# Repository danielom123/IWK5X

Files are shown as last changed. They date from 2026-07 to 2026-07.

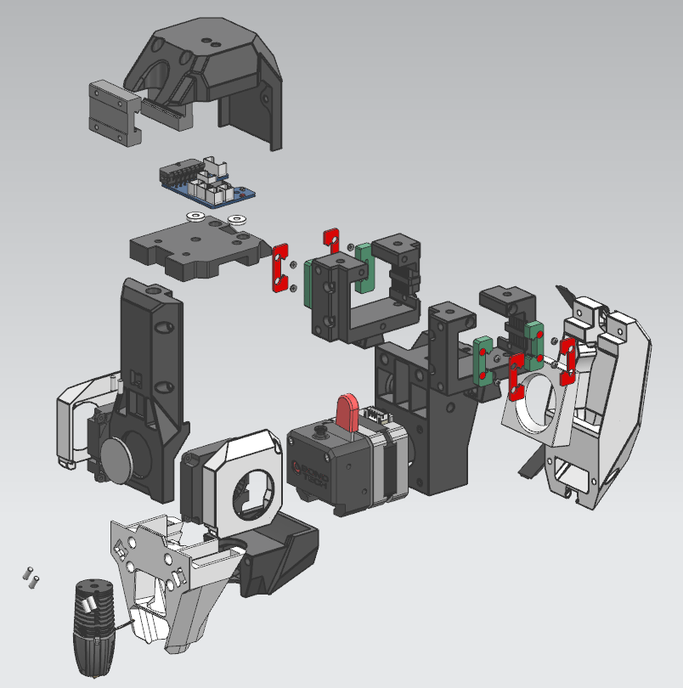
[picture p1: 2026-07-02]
STLs/Toolhead/toolhead_expl_view.png

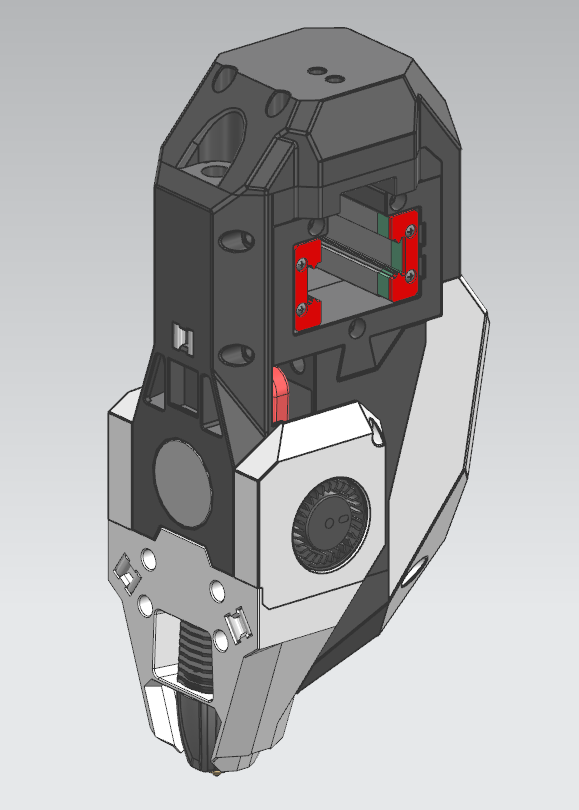
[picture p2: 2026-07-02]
STLs/Toolhead/Toolhead.png

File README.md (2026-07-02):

# IWK5X

> Developed at the [Institute for Materials Technology and Plastics Processing (IWK)](https://www.ost.ch/de/forschung-und-dienstleistungen/technik/maschinentechnik/iwk-institut-fuer-werkstofftechnik-und-kunststoffverarbeitung),
> OST – Ostschweizer Fachhochschule, Rapperswil, Switzerland
>
> **Authors:** Daniel Omidvarkarjan, Daniel Aeschbacher, Simon Grimm, Cedric Kundert
>
> **Paper:** *IWK 5X – An Open-Source Multi-Axis, Multi-Material 3D Printer for Material Extrusion*
> Procedia CIRP 142 (2026) 369–373 · [doi:10.1016/j.procir.2026.05.276](https://doi.org/10.1016/j.procir.2026.05.276)

---
PXL_20230619_124147241 PORTRAIT~2

---

## Overview

The IWK 5X is a custom 5-axis Fused Filament Fabrication (FFF) 3D printer developed at OST's IWK department. It extends a [Voron 2.4r2](https://github.com/VoronDesign/Voron-2) CoreXY platform with an AC-trunnion bridge that adds two rotational degrees of freedom:

| Axis | Rotation about | Type |
| ---- | --- | --- |
| A | Y-axis | Tilt (swivel) |
| C | Z-axis | Rotation |

The additional axes allow complex geometries to be printed without support structures and enable print paths to be oriented along stress flow, improving part strength and surface quality compared to conventional planar MEX.

The complete design files, BOM, and firmware configuration are released for open-source use in this repository.

---

## Hardware

| Component | Details |
| --- | --- |
| Base chassis | Voron 2.4 (CoreXY) |
| Rotational mechanism | AC-trunnion bridge |
| Build volume | Ø220 × 195 mm |
| Structural parts | SLS polyamide 12 (or FFF) |
| Control electronics  | Duet3 WiFi mainboard + DuetX5 expansion |
| Firmware | RepRapFirmware (RRF) |
| Tool changer | Manual - BIQU Hermit Crab V2.0 mechanical interface with custom PCB |
| Printing bed | Heated bed or aluminium mounting plate (interchangeable) |

### Supported Tool Heads

| Process | Description |
| --- | --- |
| FFF | Fused filament fabrication (standard filament extrusion) |
| FGF | Fused granulate fabrication (e.g. Metexon MTX extruder) |
| Fluid extrusion | Viscous materials, silicones (e.g. Viscotec vipro-HEAD 3/3) |
| Post-processing | Milling head and other add-ons via the tool changer interface |

The tool changer interface supports 3 stepper motors, 2 heaters, and 5 temperature sensors/fans.

---

## Software

| Layer | Technology |
| --- | --- |
| Firmware | [RepRapFirmware](https://github.com/Duet3D/RepRapFirmware) via Duet Web Control (DWC) frontend |
| CAM / slicing | Custom Rhinoceros plugin |
| Slicing modes | Conformal, concentric, curvilinear |

---

## Related Work & Extensions

- **Voron 2.4:** [vorondesign.com](https://vorondesign.com/)
- **RepRapFirmware:** [github.com/Duet3D/RepRapFirmware](https://github.com/Duet3D/RepRapFirmware)

---

## Citation

If you use this work, please cite the original publication:

```bibtex
@article{omidvarkarjan2026iwk5x,
  title   = {{IWK 5X} -- An Open-Source Multi-Axis, Multi-Material {3D} Printer for Material Extrusion},
  author  = {Omidvarkarjan, Daniel and Aeschbacher, Daniel and Grimm, Simon and Kundert, Cedric},
  journal = {Procedia CIRP},
  volume  = {142},
  pages   = {369--373},
  year    = {2026},
  doi     = {10.1016/j.procir.2026.05.276}
}
```

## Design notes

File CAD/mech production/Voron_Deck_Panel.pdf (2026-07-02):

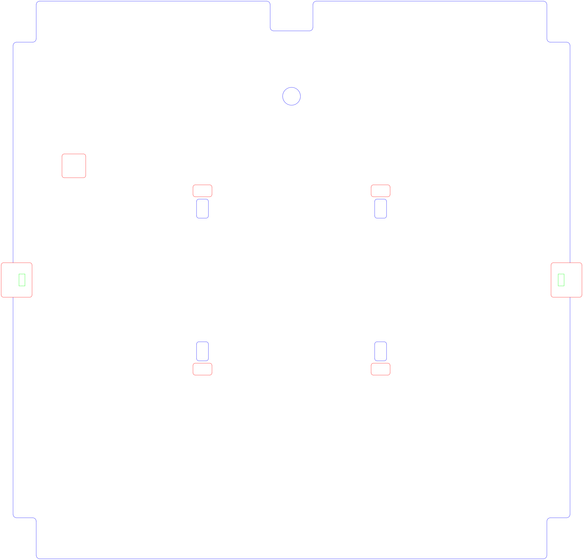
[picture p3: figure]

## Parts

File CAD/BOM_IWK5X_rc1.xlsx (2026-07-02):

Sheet: Voron
Order list |  |  |  |  |  |  | Total price | 4553.88 | CHF |  | Legend
 |  |  |  |  |  |  |  |  |  |  | can be ordered
Subject | 5-axis 3D printer |  |  |  |  |  |  |  |  |  | ordered
 |  |  |  |  |  |  |  |  |  |  | arrived
Pos | Description | Part number | Internal/External | Source | Link | Qty | Unit price | Total price | OK | Comment | under clarification
10 | Power supply 24V 400W | E3D-E-PSU-24V-400W | External | 3DJAKE | Link (https://www.3djake.ch/de-CH/e3d/netzteil) | 1 | 61.30 | 61.30 |  |  | not needed
20 | Linear rail 12mmx400m | 1901044.31 | External | 3dWare | Link (https://www.3dware.ch/Schwarz-eloxierte-Linearschiene-12mm-/-400mm-lang-De.htm) | 1 | 37.95 | 37.95
30 | Rapido Plus Hotend HF Black | PH-A158-05B-15-03 | External | 3DJAKE | Link (https://www.3djake.ch/de-CH/phaetus/rapido-plus-hotend-hf?sai=12879) | 1 | 112.40 | 112.40
40 | Voron 2.4 350mm Rev.A Black | PHWVO0010V.3 | External | 3Dmensionals | Link (https://www.3dmensionals.de/ldo-motors-voron-v2.4r2-drucker-bausatz?number=PHWVO0010V.3) | 1 | 1591.34 | 1591.34
50 | Duet 2 Wifi | 1900348.7 | External | 3dWare | Link (https://www.3dware.ch/Duet-2-Wifi-V1.04-De.htm) | 1 | 242.95 | 242.95
60 | DueX 5 Expansion Board | 1900348.5 | External | 3dWare | Link (https://www.3dware.ch/DueX5-Erweiterungsplatine-f%C3%BCr-Duet-De.htm) | 1 | 139.95 | 139.95
70 | 3D Probe Ø6mm + Spare stylus | n/a | External | Aliexpress | Link (https://www.aliexpress.com/item/1005003466415556.html?curPageLogUid=CYnIz35qAo8W) | 1 | 56.27 | 56.27
80 | Microswitch + PCB | 1900723.1 | External | 3dWare | Link (https://www.3dware.ch/Creality-Endschalter-De.htm) | 5 | 4.95 | 24.75
81 | Power cable CH | 1900824.1 | External | 3dWare | Link (https://www.3dware.ch/CH-Netzkabel-3-polig-auf-C13-De.htm) | 1 | 5.20 | 5.20
90 | Nozzle 0.4mm Bondtech CHT BiMetal | BTE-600-A-CHT-MOS-175-40 | External | 3DJAKE | Link (https://www.3djake.ch/de-CH/bondtech/cht-bimetal-reprap-duese?sai=14008) | 1 | 47.95 | 47.95
100 | Nozzle 0.6mm Bondtech CHT BiMetal | BTE-600-A-CHT-MOS-175-60 | External | 3DJAKE | Link (https://www.3djake.ch/de-CH/bondtech/cht-bimetal-reprap-duese?sai=14009) | 1 | 47.95 | 47.95
110 | Bondtech LGX Extruder | BTE-EXT-LGX | External | 3DJAKE | Link (https://www.3djake.ch/de-CH/bondtech/lgx-extruder) | 1 | 118.70 | 118.70
120 | Slip ring 8P 10A | 421546 | External | Bastelgarage | Link (https://www.bastelgarage.ch/8p-10a-elektrischer-schleifring-250rpm?search=drehdurchf%C3%BChrung) | 1 | 36.90 | 36.90
130 | Nema 23 2.8A 8mm Stepper | 1900509.876 | External | 3dWare | Link (https://www.3dware.ch/NEMA-23-Schrittmotor-XL-1.8-Grad,-2.8A-/-8mm-De.htm) | 1 | 48.95 | 48.95
140 | Nema 17 1.5A 5mm Stepper | 421173 | External | Bastelgarage | Link (https://www.bastelgarage.ch/creality-42-34-stepper-motor-nema-17-schrittmotor?search=nema%2017) | 1 | 19.90 | 19.90
150 | Limit switch roller | 421472 | External | Bastelgarage | Link (https://www.bastelgarage.ch/kw1-103-7-micro-rollenschalter-endschalter?search=endschalter) | 2 | 2.50 | 5.00
160 | Pulley GT2 6mm 20T | 1900952.2 | External | 3dWare | Link (https://www.3dware.ch/GT2-Riemenscheibe-20-Z%C3%A4hne-CoreXY-5mm-Bohrung-De.htm) | 1 | 3.80 | 3.80
170 | Wire AWG24 Black 100m | 422200 | External | Bastelgarage | Link (https://www.bastelgarage.ch/kabel-litzen/litzen-drahte/litze-0-25mm-schwarz-lify-hochflexibel-100m) | 1 | 32.90 | 32.90
171 | Wire AWG20 Black 10m | 420752 | External | Bastelgarage | Link (https://www.bastelgarage.ch/kabel-litzen/litzen-drahte/litze-0-5mm-20awg-schwarz-halogenfrei) | 10 | 0.55 | 5.50
180 | Wire AWG17 black 10m | 1900859.22 | External | 3dWare | Link (https://www.3dware.ch/Litzen-Kabel-1.00-mm178-Schwarz-10-Meter-De.htm) | 1 | 7.45 | 7.45
190 | Fan 4020 24V | 421794 | External | Bastelgarage | Link (https://www.bastelgarage.ch/4020-silent-lufter-24v-radial-reparaturset?search=l%C3%BCfter) | 1 | 7.90 | 7.90
200 | Crimping tool JST/ Dupont/ Molex | 420674 | External | Bastelgarage | Link (https://www.bastelgarage.ch/crimpzange-2820m-0-08-0-5mm?search=crimpzange) | 1 | 34.90 | 34.90
210 | JST XH Set 2.54mm | 420207 | External | Bastelgarage | Link (https://www.bastelgarage.ch/jst-xh-crimp-stecker-und-buchsen-2-54mm-set-40-stuck?search=jst) | 1 | 13.90 | 13.90
220 | JST PH Set 2.0mm | 420381 | External | Bastelgarage | Link (https://www.bastelgarage.ch/jst-ph-crimp-stecker-und-buchsen-2mm-set-40-stuck?search=jst) | 1 | 13.90 | 13.90
230 | Dupont Crimp Set | 420382 | External | Bastelgarage | Link (https://www.bastelgarage.ch/dupont-crimp-stecker-und-buchsen-set-620-stuck?search=dupont) | 1 | 19.50 | 19.50
240 | Capricorn PTFE 2m | CC-XS-175-2 | External | 3DJAKE | Link (https://www.3djake.ch/de-CH/capricorn/xs-ultra-low-friction-ptfe-bowden?sai=3645) | 1 | 25.55 | 25.55
250 | Bondtech LGX Hardened Steel Drive | BTE-15147 | External | 3DJAKE | Link (https://www.3djake.ch/de-CH/bondtech/lgx-steel-drive-train-upgrade-set) | 1 | 42.90 | 42.90
260 | Fan 4010 24V | CRE-4004110083 | External | 3DJAKE | Link (https://www.3djake.ch/de-CH/creality-3d-drucker-ersatzteile/radial-luefter-kit?sai=11411) | 2 | 5.10 | 10.20
270 | Switching regulator | 420478 | External | Bastelgarage | Link (https://www.bastelgarage.ch/mp1584-3a-schaltregler-dc-dc-step-down-abwartswandler?search=step%20down) | 2 | 2.90 | 5.80
290 | Assortment box 15 compartments | 420253 | External | Bastelgarage | Link (https://www.bastelgarage.ch/sortimentskasten-mittel-15-facher?search=sortiment) | 3 | 3.90 | 11.70
300 | Drag chain 10x10mm | 421229 | External | Bastelgarage | Link (https://www.bastelgarage.ch/10x10mm-nylon-kabelschlepp-1m?search=kabelschlepp) | 1 | 13.90 | 13.90
310 | Heated bed D200 | FLS-Q5-HOTBED | External | 3DJAKE | Link (https://www.3djake.ch/de-CH/flsun/heizbett-inkl-druckplattform) | 1 | 30.65 | 30.65
320 | Flexplate D203 | BT-BTFS08DIA | External | 3DJAKE | Link (https://www.3djake.ch/de-CH/buildtak/flexplate-system?sai=7832) | 1 | 65.39 | 65.39
340 | Keystone USB C to A | 1009503 | External | Brack | Link (https://www.brack.ch/delock-keystone-modul-usb2-0-usb-a-usb-c-1009503) | 1 | 11.45 | 11.45
350 | Slewing ring | PRT-02.50-LC | External | igus | Link (https://www.igus.ch/product/iglidur_PRT_02_LC_J4?artnr=PRT-02-50-LC) | 1 | 99.93 | 99.93
380 | JST SM Set 2.54mm | 421196 | External | Bastelgarage | Link (https://www.bastelgarage.ch/jst-sm-2-54mm-crimp-stecker-und-buchsen-set-40-stuck?search=jst) | 1 | 11.90 | 11.90
390 | Carbon tube D10 d8 1m | 421890 | External | Bastelgarage | Link (https://www.bastelgarage.ch/mechanische-bauteile/cfk-stabe-rohre/carbon-rohr-o8xo10mm-1m) | 1 | 10.50 | 10.50
400 | KP08 Bearing block | 1900956.1 | External | 3dWare | Link (https://www.3dware.ch/KP08-8mm-Bohrung-Zinklegierung-Lagerwelle-De.htm) | 4 | 3.00 | 12.00
410 | Belt GT2 9mm 450mm | 1900950.45 | External | 3dWare | Link (https://www.3dware.ch/GT2-Riemen-9mm-breit-450mm-lang-De.htm) | 1 | 2.30 | 2.30
411 | Belt GT2 6mm 480mm | 1900920.48 | External | 3dWare | Link (https://www.3dware.ch/GT2-Riemen-6mm-breit-480mm-lang-De.htm) | 1 | 2.20 | 2.20
420 | Pulley GT2 9mm 20T | 1900949.2 | External | 3dWare | Link (https://www.3dware.ch/GT2-9mm-Riemenscheibe-20-Z%C3%A4hne-8mm-Bohrung-De.htm) | 1 | 4.20 | 4.20
430 | Pulley GT2 6mm 40T | 1900944.4 | External | 3dWare | Link (https://www.3dware.ch/GT2-Riemenscheibe-40-Z%C3%A4hne-8mm-Bohrung-De.htm) | 2 | 5.95 | 11.90
440 | Pulley GT2 9mm 60T | 1900949.6 | External | 3dWare | Link (https://www.3dware.ch/GT2-9mm-Riemenscheibe-60-Z%C3%A4hne-8mm-Bohrung-De.htm) | 1 | 8.20 | 8.20
450 | XT30 Connector | 422220 | External | Bastelgarage | Link (https://www.bastelgarage.ch/xt30-stecker-male-und-female?search=xt30) | 3 | 4.50 | 13.50
460 | Solder | 421633 | External | Bastelgarage | Link (https://www.bastelgarage.ch/werkstattbedarf/lotstation-und-zubehor/engineer-swf-08-lotzinn-14g-bleifrei-0-8mm-sn96-5-ag3-cu0-5) | 1 | 15.90 | 15.90
470 | Flange bearing F695ZZ | 1900911.27 | External | 3dWare | Link (https://www.3dware.ch/Rillenkugellager-mit-Flansch-F695ZZ-De.htm) | 8 | 1.50 | 12.00
489 | Threaded insert M3 50pcs | 422091 | External | Bastelgarage | Link (https://www.bastelgarage.ch/3d-drucker/zubehor-3d-druck/m3x6mm-gewindeeinsatze-messing-insert-50stk) | 1 | 6.90 | 6.90
490 | Threaded insert M5 50pcs | 422201 | External | Bastelgarage | Link (https://www.bastelgarage.ch/3d-drucker/zubehor-3d-druck/m5x8mm-gewindeeinsatze-messing-insert-50stk) | 1 | 10.90 | 10.90
491 | Threaded insert M6 50pcs | 422202 | External | Bastelgarage | Link (https://www.bastelgarage.ch/m6x8mm-gewindeeinsatze-messing-insert-50stk?search=gewinde) | 1 | 14.90 | 14.90
500 | Electromagnet 8kg | 421586 | External | Bastelgarage | Link (https://www.bastelgarage.ch/mechanische-bauteile/magnete/5v-elektromagnet-8kg-haftkraft) | 1 | 9.50 | 9.50
510 | Relay 2-channel | 420010 | External | Bastelgarage | Link (https://www.bastelgarage.ch/2-kanal-relais-modul-5v?search=relais) | 1 | 6.90 | 6.90
520 | Heat shrink tubing | 420029 | External | Bastelgarage | Link (https://www.bastelgarage.ch/werkstattbedarf/diverses/schrumpfschlauch-set-diverse-farben-55-stuck-total-15m) | 1 | 9.90 | 9.90
530 | Switching regulator | 420103 | External | Bastelgarage | Link (https://www.bastelgarage.ch/lm2596-schaltregler-dc-dc-step-down-abwartswandler?search=step-down) | 2 | 4.90 | 9.80
540 | Push button Green | 420330 | External | Bastelgarage | Link (https://www.bastelgarage.ch/bauteile/schalter-taster/arcade-taster-button-beleuchtet-33mm-grun) | 1 | 4.50 | 4.50
550 | Push button Red | 420328 | External | Bastelgarage | Link (https://www.bastelgarage.ch/bauteile/schalter-taster/arcade-taster-button-beleuchtet-33mm-rot) | 1 | 4.50 | 4.50
560 | Cable ties 3mm 100pcs | 420646 | External | Bastelgarage | Link (https://www.bastelgarage.ch/werkstattbedarf/diverses/schwarze-3x100mm-nylon-kabelbinder-100-stuck) | 1 | 3.90 | 3.90
570 | 2K Epoxy UHU | 422137 | External | Bastelgarage | Link (https://www.bastelgarage.ch/werkstattbedarf/klebstoff-epoxidharze/uhu-plus-endfest-zweikomponenten-epoxidkleber-33g) | 1 | 12.90 | 12.90
590 | Printed parts SLS/FFF |  | External | JLC3DP | Link (https://jlc3dp.com/de?spm=Jlc3dp.Homepage.1001) | 1 |  | 0.00
600 | Base plate |  | External | JLCCNC | Link (https://jlccnc.com/) | 1 | 300.00 | 300.00
610 | Kinematic components swivel table |  | Internal | Mech-Workshop |  | 1 | 1000.00 | 1000.00
620 |  |  |  |  |  |  |  | 0.00
630 |  |  |  |  |  |  |  | 0.00
640 |  |  |  |  |  |  |  | 0.00
650 |  |  |  |  |  |  |  | 0.00
660 |  |  |  |  |  |  |  | 0.00
670 |  |  |  |  |  |  |  | 0.00
680 |  |  |  |  |  |  |  | 0.00
690 |  |  |  |  |  |  |  | 0.00
700 |  |  |  |  |  |  |  | 0.00
710 |  |  |  |  |  |  |  | 0.00
720 |  |  |  |  |  |  |  | 0.00
730 |  |  |  |  |  |  |  | 0.00

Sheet: Dropdowns
Int/Ext | Supplier
Internal | 3dWare
External | Mädler
 | Schweighofer
 | Galaxus
 | Bastelgarage
 | Amazon
 | Mech-Workshop
 | Blexon
 | Durovis
 | Aliexpress
 | 3DJAKE
 | 3Dmensionals
 | igus
 | Brack
 | IWK
 | JLC3DP
 | JLCCNC

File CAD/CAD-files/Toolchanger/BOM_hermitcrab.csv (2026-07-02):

ID | Name | Designator | Footprint | Quantity | Manufacturer Part | Manufacturer | Supplier | Supplier Part | Price | Pins | 3DModel
1 | XD-ZH-12PWT | U1 | CONN-SMD_12P-P1.50_HCTL_HC-ZH-12PWT | 1 | XD-ZH-12PWT | XUNDA(讯答) | LCSC | C17700467 | 0.167 | 14 | CONN-SMD_12P-P1.50_HCTL_HC-ZH-12PWT
2 | MX128-2.54-04P-GN01-CU-Y-A | HOTENDS | CONN-TH_4P-P2.54_MX128-2.54-GN01-04P-CU-Y-A | 1 | MX128-2.54-04P-GN01-Cu-Y-A | MAX(迈旭) | LCSC | C5188444 | 0.375 | 4 | CONN-TH_4P-P2.54_MX128-2.54-GN01-04P-CU-Y-A
3 | _ | NONE |  | 1
4 | YTC1P-3010-01 | CN1,CN3,CN4,CN5,CN6,CN7,CN8,CN9,CN10,CN11,CN12,CN13,CN14,CN15,CN16,CN17,CN18,CN19,CN20,CN21,CN22,CN23,CN24,CN25 | TESTPOINT-SMD_BD2.0_C9900030651 | 24 | YTC1P-3010-01 | YIYUAN(怡远) | LCSC | C5221282 | 0.134 | 1
5 | YZ90415045R-01 | U3,U6,U9,U10,U11,U12,U13,U14 | SMD-1_BD2.0-H10.0 | 8 | YZ90415045R-01 | Xinyangze(鑫扬泽) | LCSC | C5157399 | 0.395 | 1 | SMD-1_BD2.0-H10.0
6 | HDGC1002WVD-S-2X6P | LOWPOWER | CONN-SMD_12P-P1.00_HDGC_HDGC1002WVD-S-2X6P | 1 | HDGC1002WVD-S-2X6P | HDGC(华德共创) | LCSC | C3041208 | 0.433 | 14 | CONN-SMD_12P-P1.00_HDGC_HDGC1002WVD-S-2X6P

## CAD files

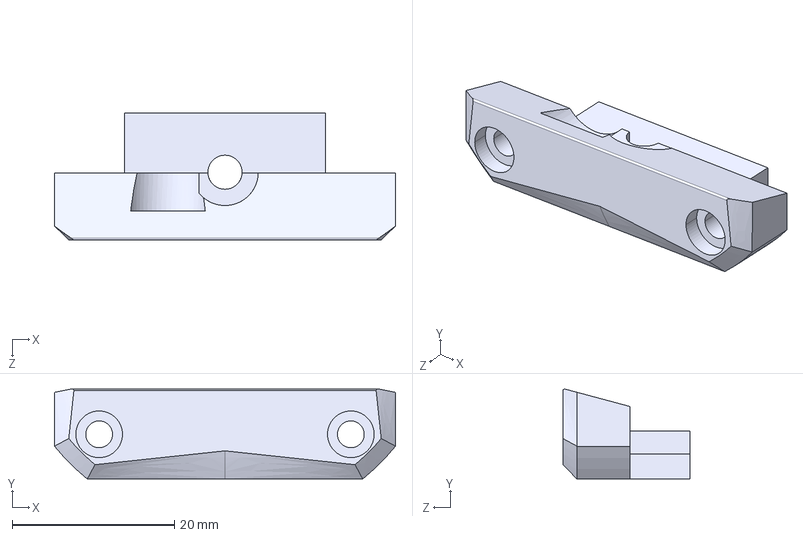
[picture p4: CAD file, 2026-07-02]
CAD/bought-in parts/LGX-Interface-Plug-V1.0.STEP
42.0 x 11.1 x 15.7 mm

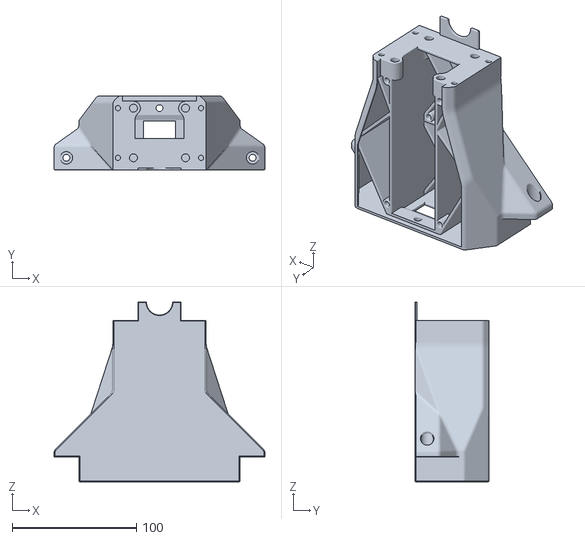
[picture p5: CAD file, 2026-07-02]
STLs/ac_bridge/tronnion_sidepillar_right.stl
170.0 x 60.0 x 145.0

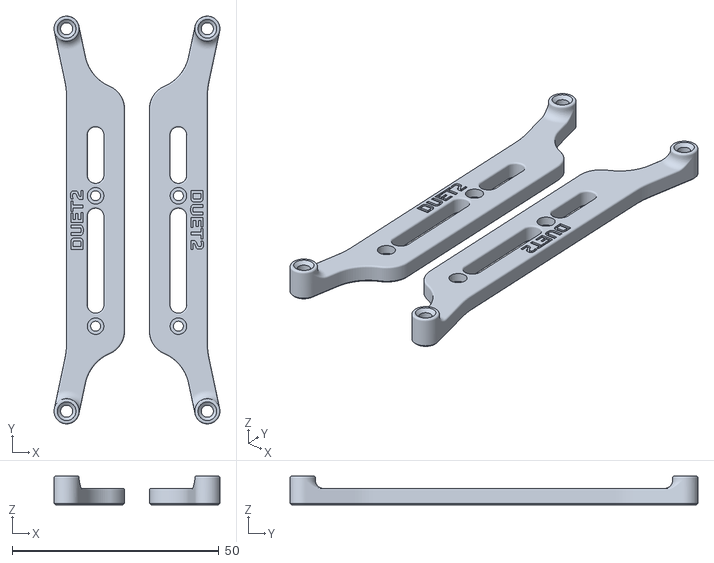
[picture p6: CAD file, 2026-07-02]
STLs/Electronics_Bay/Controller_Mounts/Duet2_Duet3Mini5_bracket_set.stl
40.1 x 98.5 x 7.00

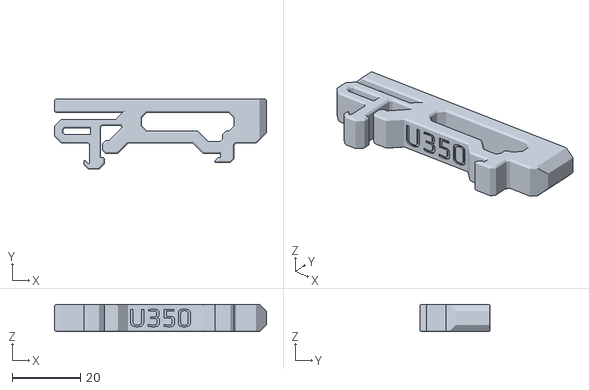
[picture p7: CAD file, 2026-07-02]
STLs/Electronics_Bay/Other_PS_Mounts/UHP_350_Mount_x2.stl
62.0 x 20.6 x 8.00

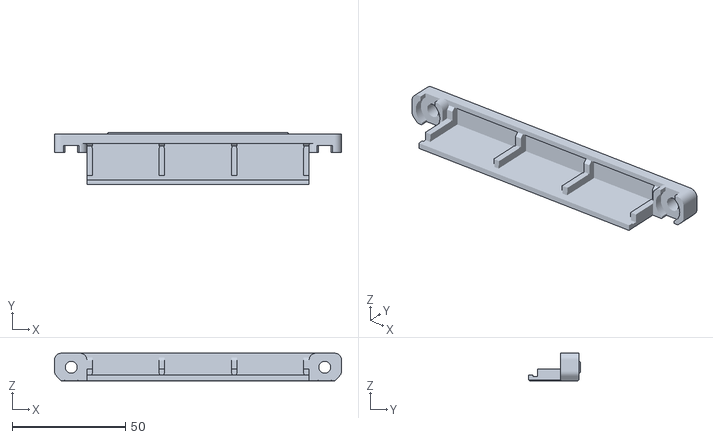
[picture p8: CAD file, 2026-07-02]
STLs/Electronics_Bay/wago_221-415_mount_3by5.stl
126.8 x 23.0 x 12.2

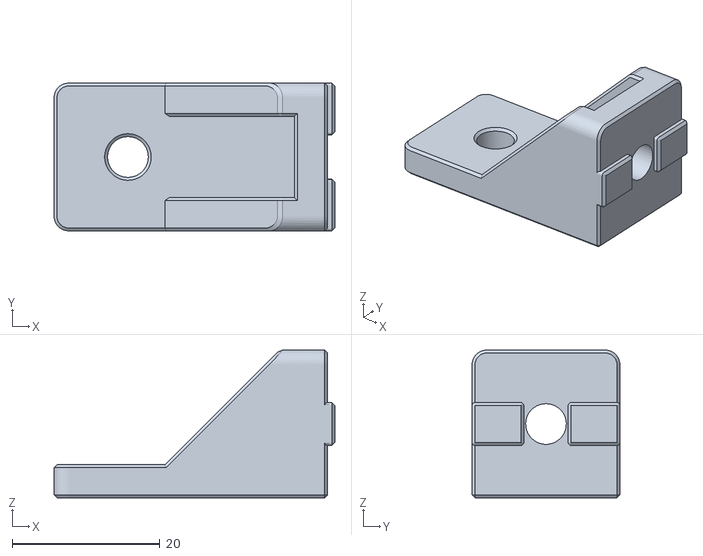
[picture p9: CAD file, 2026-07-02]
STLs/Frame/pillar_brace_x4.stl
38.0 x 20.0 x 20.0

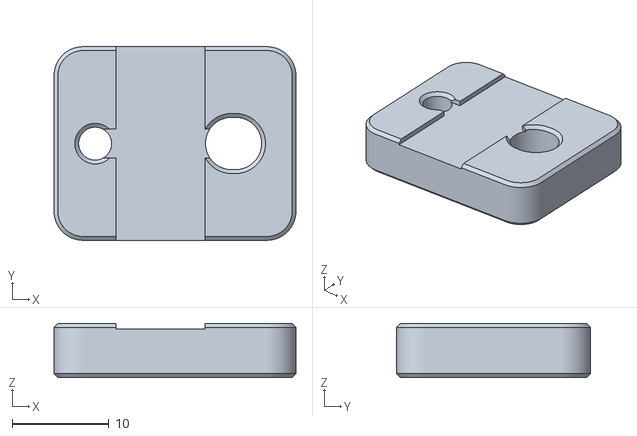
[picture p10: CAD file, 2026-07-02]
STLs/Gantry/[a]_z_belt_clip_lower_x4.stl
25.0 x 20.0 x 5.60

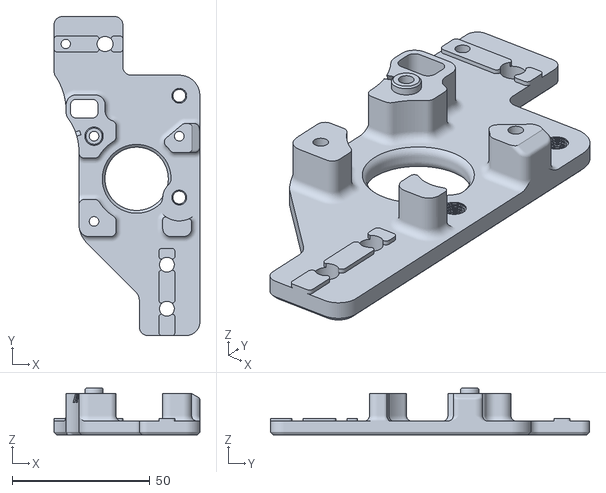
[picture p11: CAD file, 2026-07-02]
STLs/Gantry/AB_Drive_Units/b_drive_frame_lower.stl
53.0 x 116.0 x 17.0

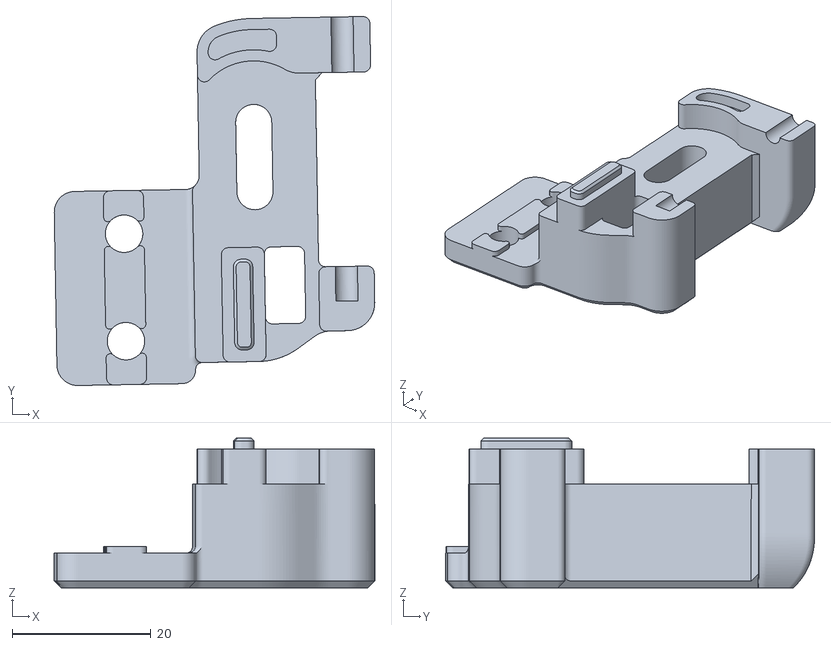
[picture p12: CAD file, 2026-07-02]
STLs/Gantry/Front_Idlers/front_idler_left_upper.stl
46.2 x 53.2 x 21.6

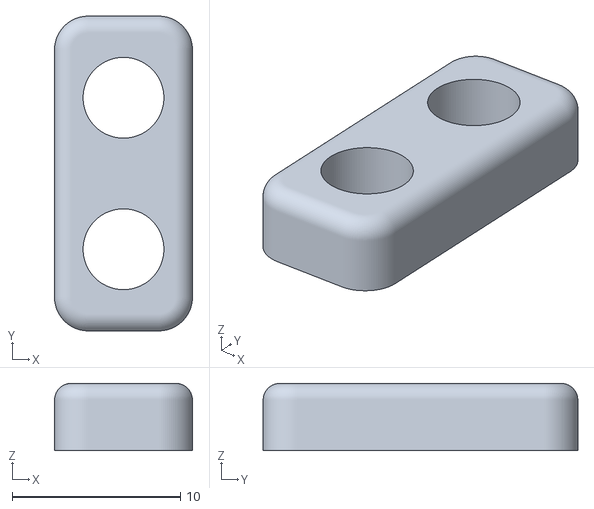
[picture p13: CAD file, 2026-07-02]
STLs/Gantry/X_Axis/X_Carriage/probe_retainer_bracket_9mm.stl
8.20 x 18.7 x 4.00

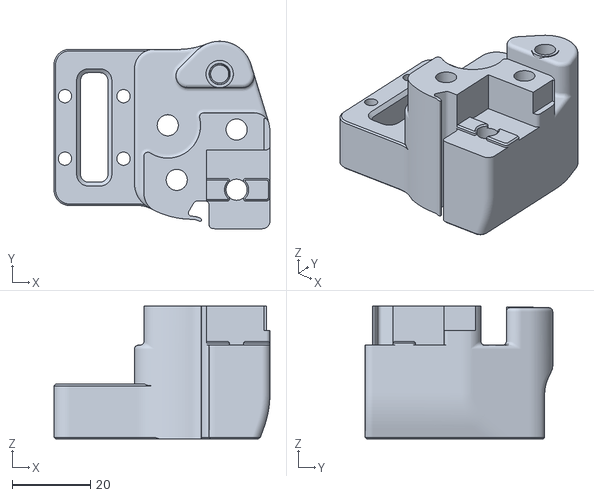
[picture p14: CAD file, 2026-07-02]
STLs/Gantry/X_Axis/XY_Joints/xy_joint_right_lower_MGN12.stl
55.3 x 48.0 x 34.0

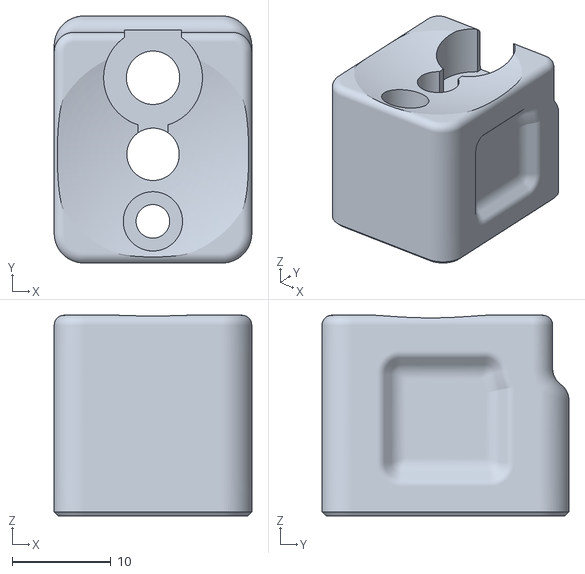
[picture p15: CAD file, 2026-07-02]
STLs/Gantry/Z_Joints/z_joint_upper_x4.stl
20.0 x 25.0 x 20.3

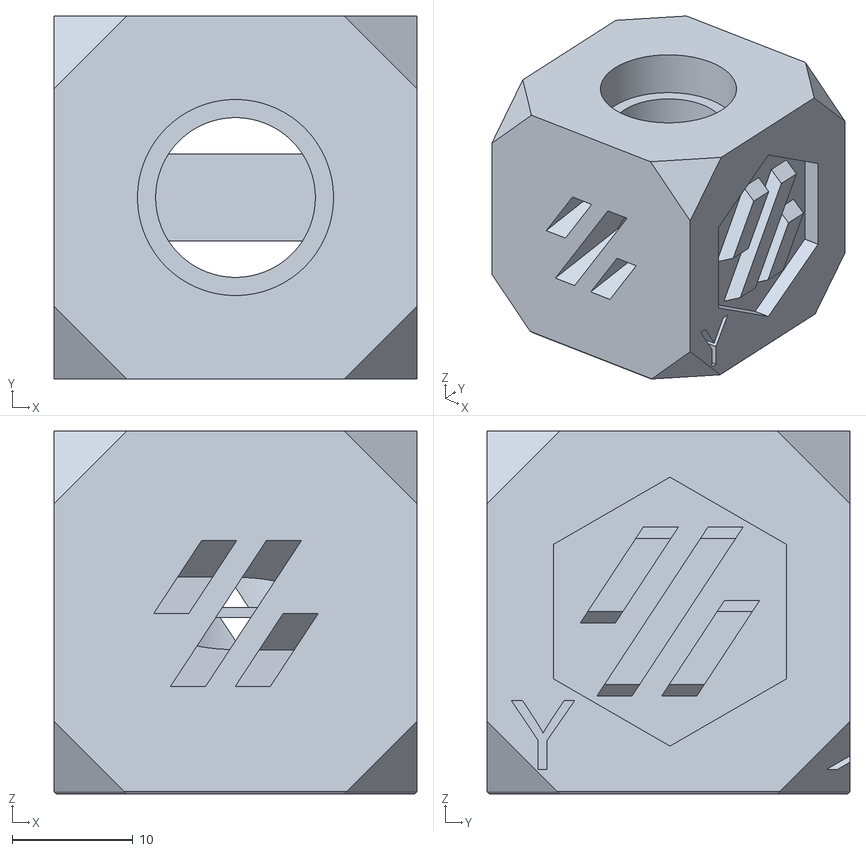
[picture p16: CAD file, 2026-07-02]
STLs/Test_Prints/Voron_Design_Cube_v7.stl
30.0 x 30.0 x 30.0

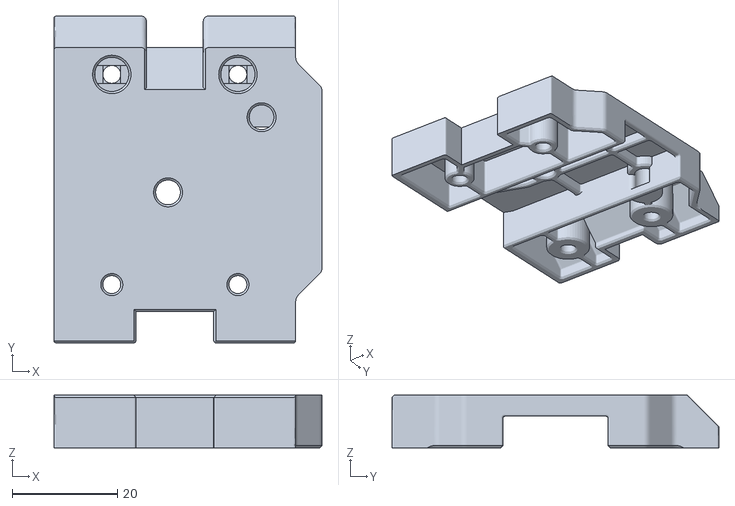
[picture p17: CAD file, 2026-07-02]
STLs/Toolhead/carriage_pcb_holder.stl
51.0 x 62.2 x 10.0

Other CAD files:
CAD/CAD-files/IWKX5_Master.stp
CAD/mech production/Baseplate.stp
STLs/Tools/MGN9_rail_guide_x2.stl
CAD/mech production/Voron_Deck_Panel.dxf
STLs/Electronics_Bay/Controller_Mounts/din_rail_endcap_x4.stl
STLs/Electronics_Bay/Controller_Mounts/duet3exp_expander.stl
STLs/Electronics_Bay/Controller_Mounts/duet3mb_expander.stl
STLs/Electronics_Bay/Other_PS_Mounts/UHP_200_Mount_x2.stl
STLs/Electronics_Bay/alt_raspberrypi_bracket.stl
STLs/Electronics_Bay/lrs_200_psu_bracket_x2.stl
STLs/Electronics_Bay/pcb_din_clip_x4.stl
STLs/Electronics_Bay/raspberrypi_expander.stl
STLs/Frame/90deg_corner_(OpenBuilds)_x4.stl
STLs/Gantry/AB_Drive_Units/[a]_cable_cover.stl
STLs/Gantry/AB_Drive_Units/[a]_z_chain_retainer_bracket_x2.stl
STLs/Gantry/AB_Drive_Units/a_drive_frame_lower.stl
STLs/Gantry/AB_Drive_Units/a_drive_frame_upper.stl
STLs/Gantry/AB_Drive_Units/b_drive_frame_upper.stl
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

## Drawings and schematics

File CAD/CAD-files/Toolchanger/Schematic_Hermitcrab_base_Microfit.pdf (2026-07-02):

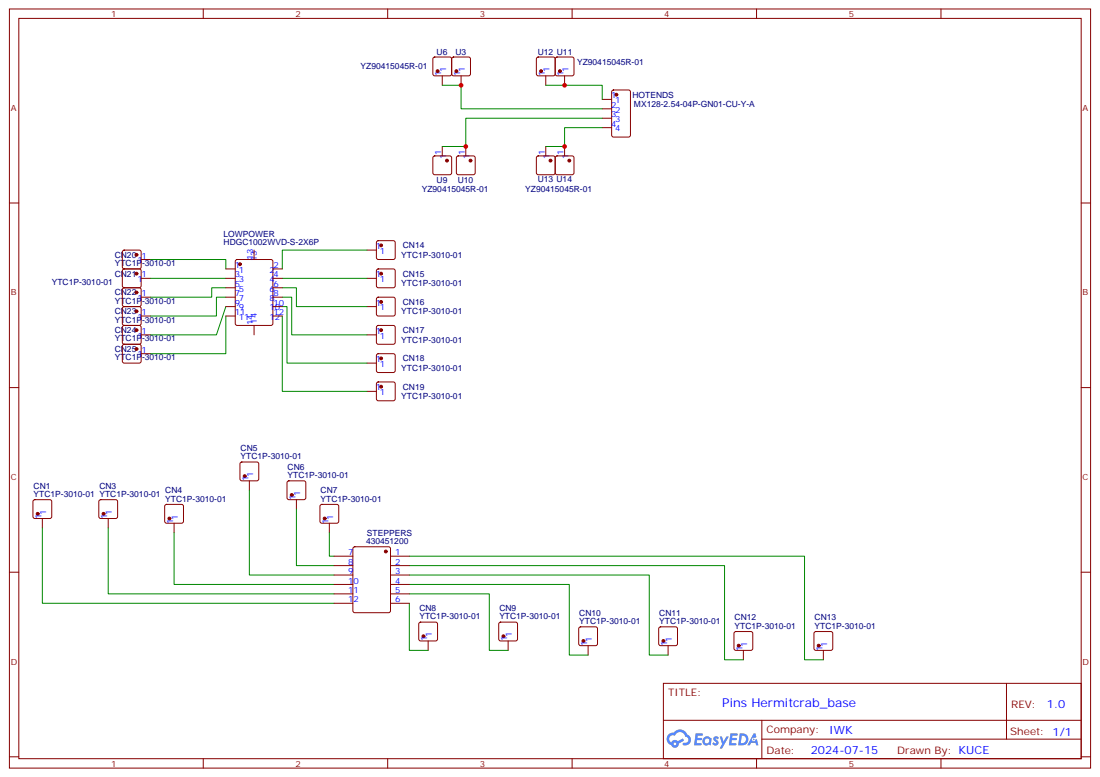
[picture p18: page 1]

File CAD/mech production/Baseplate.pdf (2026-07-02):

A-A

A

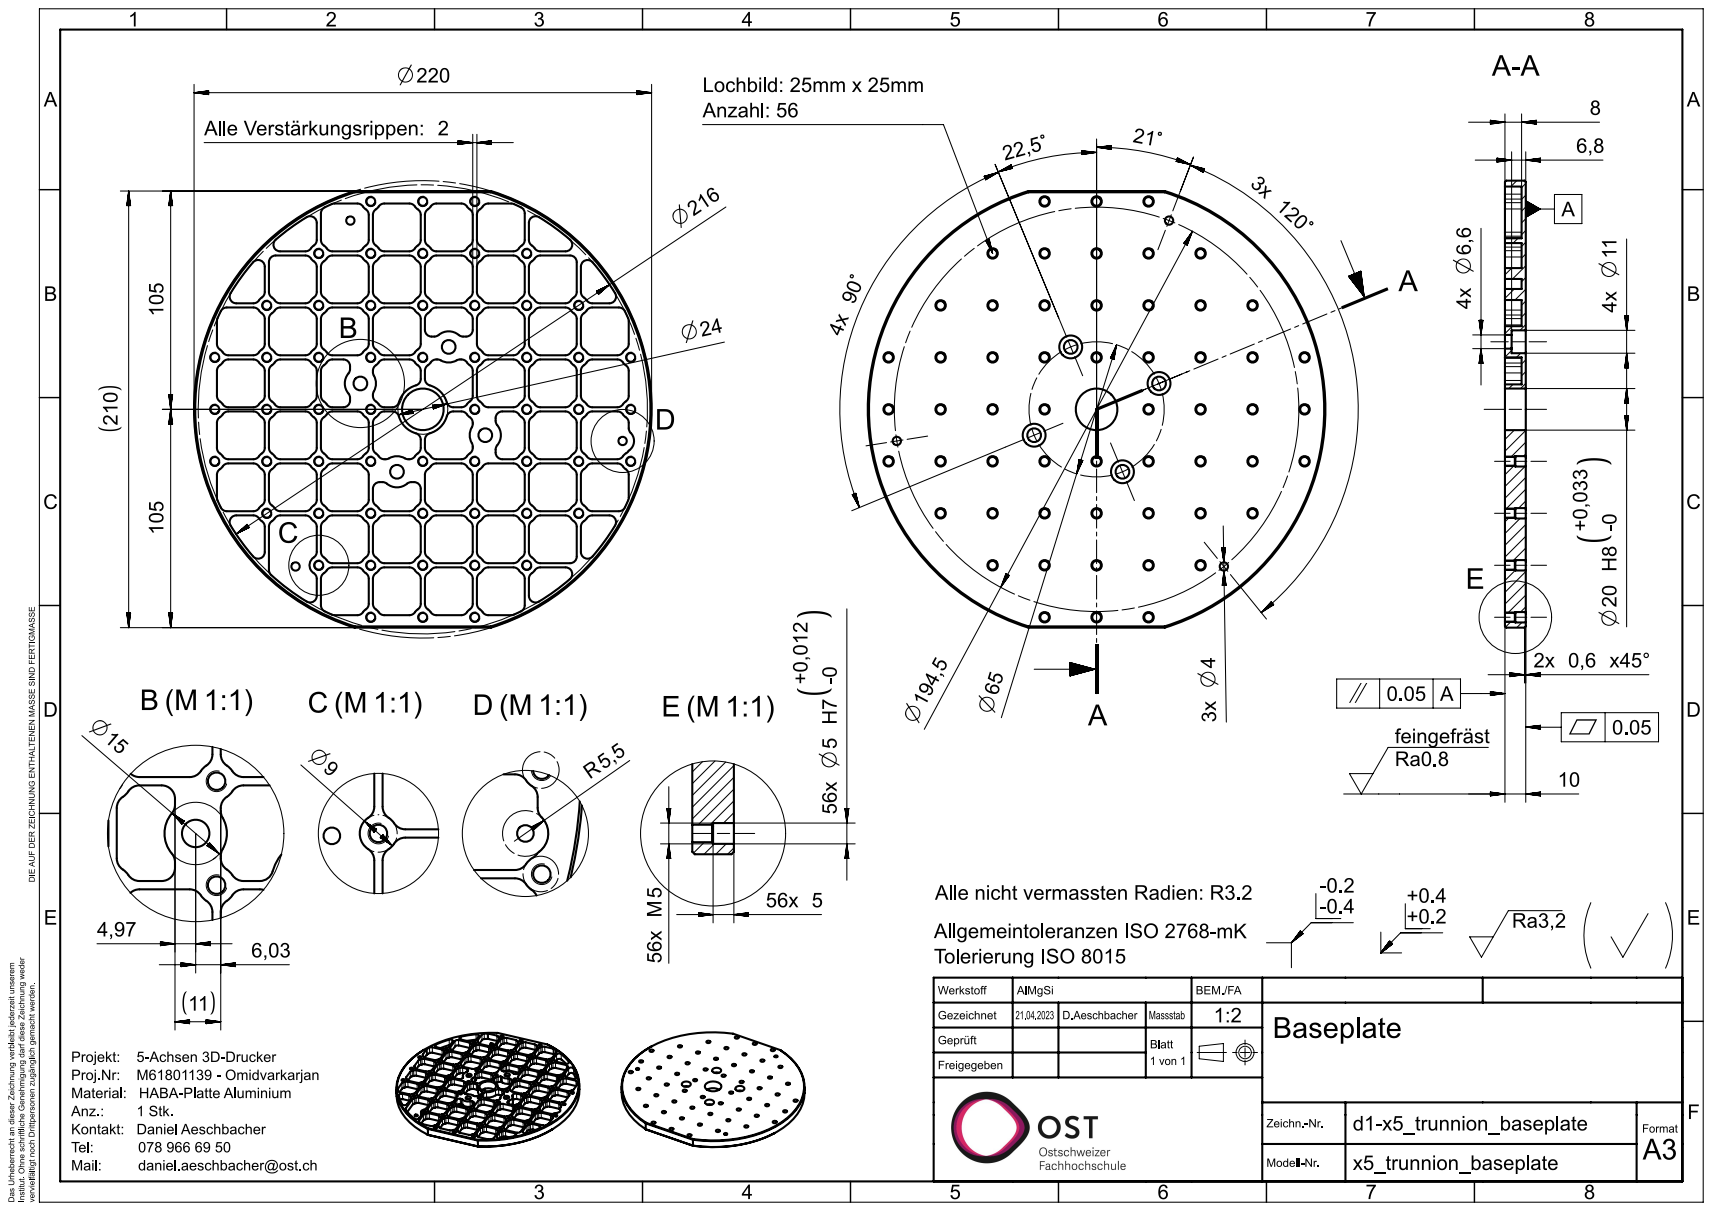
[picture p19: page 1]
Werkstoff; AlMgSi; BEM./FA; Gezeichnet; 21.04.2023 D.Aeschbacher Massstab; Geprüft; Baseplate Blatt; Freigegeben; 1 von 1; Zeichn.-Nr.; d1-x5_trunnion_baseplate; Format; Modell-Nr.; A3 x5_trunnion_baseplate; Allgemeintoleranzen ISO 2768- Tolerierung ISO 8015; Projekt:; 5-Achsen 3D-Drucker; Proj.Nr:; M61801139 - Omidvarkarjan; Material:; HABA-Platte Aluminium; Anz.:; 1 Stk.; Kontakt:; Daniel Aeschbacher; Tel:; Mail:; daniel.aeschbacher@ost.ch; Alle Verstärkungsrippen: 2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

vervielfältigt noch Drittpersonen zugänglich gemacht werden. DIE AUF DER ZEICHNUNG ENTHALTENEN MASSE SIND FERTIGMASSE

Alle nicht vermassten Radien: R3.2

Das Urheberrecht an dieser Zeichnung verbleibt jederzeit unserem

Institut. Ohne schriftliche Genehmigung darf diese Zeichnung weder

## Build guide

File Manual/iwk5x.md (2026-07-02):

# Manual IWK5X
For assembling the IWK5X it is recommended to follow the cad. For all the base components, except ac_bridge and toolhead, it is suggested to follow the official Assembly_Manual_base_2.4r2 of the Voron Design Team.

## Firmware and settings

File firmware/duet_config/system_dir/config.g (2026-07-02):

; Configuration file for RepRapFirmware on Duet 3 Main Board 6HC
; executed by the firmware on start-up
; D.Aeschbacher 08.01.2024


; General
G90
M83
M550 P"VoronPanda" ; set hostname

; Wait a moment for the CAN expansion boards to become available
G4 S2

; Kinematics
M669 K1 ; configure CoreXY kinematics

; Smart Drivers
M569 P0.0 S0 D3 V75     ; driver 0.0 goes backwards (X/Y axis, A Motor)
M569 P0.1 S0 D3 V75     ; driver 0.1 goes backwards (X/Y axis, B motor)
M569 P0.2 S0 D2         ; driver 0.2 goes backwards (A axis), spreadcycle for more torque (audible noise)
M569 P0.3 S0 D2         ; driver 0.3 goes backwards (C axis), spreadcycle for more torque (audible noise)
M569 P0.4 S0 D3 V23     ; driver 0.4 goes backwards (extruder 0)
M569 P0.5 S1 D3 V31     ; driver 0.5 goes forwards (Z1 axis)
M569 P1.0 S0 D3 V31     ; driver 1.0 goes backwards (Z2 axis)
M569 P1.1 S1 D3 V31     ; driver 1.1 goes forwards (Z3 axis)
M569 P1.2 S0 D3 V31     ; driver 1.2 goes backwards (Z0 axis)
;M569 P2.0 S0 D0 		; driver 1.0 extruder Visco.1		
;M569 P2.1 S0 D0			; driver 1.1 extruder Visco.2		
M569 P2.0 T21:21:0:0	; minimum driver step pulse 
M569 P2.1 T21:21:0:0 	; minimum driver step pulse


; Axes
M584 X0.1 Y0.0 Z0.5:1.0:1.1:1.2 A0.2 C0.3   ; set axis mapping 
M350 X32 Y16 Z16 A16 C16 I1                 ; configure microstepping with interpolation
M92 X160 Y160 Z400 A27.266666 C66.666666    ; configure steps per mm

;V1
;M566 X480 Y480 Z24 A48 C200                ; set maximum instantaneous speed changes (mm/min)
;M203 X10800 Y10800 Z10800 A10800 C21600    ; set maximum speeds (mm/min)
;M201 X1000 Y1000 Z1000 A250 C800           ; set accelerations (mm/s^2)
;V2
;M566 X480 Y480 Z24 A48 C200                ; set maximum instantaneous speed changes (mm/min)
;M203 X3600 Y3600 Z3600 A1200 C1800         ; set maximum speeds (mm/min)
;M201 X500 Y500 Z500 A125 C400              ; set accelerations (mm/s^2)
;V3
M566 X500 Y500 Z500 A250 C250               ; set maximum instantaneous speed changes (mm/min)
M203 X3600 Y3600 Z3600 A1200 C1800          ; set maximum speeds (mm/min)
M201 X200 Y200 Z200 A100 C400               ; set accelerations (mm/s^2)

M906 X1200 Y1200 Z1200 C800                 ; set axis driver currents (mA)
M906 I30                                    ; set motor current idle factor
M906 A2200 I100                             ; set axis driver currents for A, no idle
M84 S30                                     ; set motor current idle timeout

; Axes Limits
M208 X-300:0                        ; set X axis limits
M208 Y-318:0                        ; set Y axis limits
;M208 Z-181.5:2                      ; set Z axis limits -> limit to plate
M208 Z-195:2                      ; set Z axis limits
M208 A-90:100                       ; set A axis limits
M208 C-32212000:32212000            ; set C axis limits

; Extruders
M584 E0.4       ; set extruder mapping
M350 E16 I1     ; configure microstepping with interpolation
M906 E600       ; set extruder driver currents
M92 E400        ; configure steps per mm
M566 E270       ; set maximum instantaneous speed changes (mm/min)
M203 E4800      ; set maximum speeds (mm/min)
M201 E1000      ; set accelerations (mm/s^2)

;Extruder ViscoTec-Kopf 12					
;M584 E2.0:2.1 ; set extruder mapping							
;M350 E2.0:2.1 I0 ; configure microstepping with interpolation	
;M906 E770:770 ; set extruder driver currents
;M92 E1002.17:1002.17 ; configure steps per mm !IF FILAMENTDIAMETER = 1mm IN SLICER!
;M566 E50:50 ; set maximum instantaneous speed changes (mm/min)
;M203 E2000:2000 ; set maximum speeds (mm/min)
;M201 E250:250 ; set accelerations (mm/s^2)

; Endstops
M574 X2 S1 P"io0.in"                        ; configure X axis endstop
M574 Y2 S1 P"io1.in"                        ; configure Y axis endstop
M574 Z2 S1 P"io4.in+io5.in+io7.in+io2.in"   ; configure Z axis endstop
M574 A1 S1 P"io6.in"                        ; configure A axis endstop
M574 C0 S1 P"io3.in"                        ; configure C axis endstop

; Touch-Probe
M558 P8 C"!1.io0.in" K0 H5 F300 T3000 B1 

; Heated bed
M308 S0 P"temp0" Y"thermistor" A"Heated Bed" T100000 B4138  ; configure sensor #0
M950 H0 C"out0" T0                                          ; create heater #0
M140 P0 H0                                                  ; configure heated bed #0
M143 H0 P0 T0 C0 S110 A0                                    ; configure heater monitor #0 for heater #0
M307 H0 R0.355 K0.334:0.000 D2.17 E1.35 S1.00 B0            ; configure model of heater #0, PID values from M303 auto-tune

; Heater
M308 S1 P"temp1" Y"pt1000" A"Nozzle"                        ; configure sensor #1
M950 H1 C"out2" T1                                          ; create heater #1
M143 H1 P0 T1 C0 S350 A0                                    ; configure heater monitor #0 for heater #1
M307 H1 R3.897 K0.450:0.000 D6.84 E1.35 S1.00 B0 V24.0      ; configure model of heater #1, PID values from M303 auto-tune

; Fans
M950 F0 C"out7" Q500                    ; create fan #0
M106 P0 C"Hotend Fan" S0 B0.1 H1 T50    ; configure fan #0

M950 F1 C"out8" Q500                    ; create fan #1
M106 P1 C"Part Fan" S0 L0 X1 B0.1       ; configure fan #1

M950 F2 C"out9" Q500                    ; create fan #2
M106 P2 C"C Fan" S1 L0 X1 B0.1          ; configure fan #2

M950 F3 C"1.out6" Q500                  ; create fan #3
M106 P3 C"A Fan" S0.7 L0 X1 B0.1        ; configure fan #3

M308 S10 Y"mcu-temp" A"MB-MCU"                              ; defines sensor 10 as MCU temperature sensor on MB
M308 S11 Y"mcu-temp" P"1.dummy" A"3HC-MCU"                  ; defines sensor 11 as MCU temperature sensor on 3HC
M308 S12 Y"drivers" A"MB-Drivers"                           ; defines sensor 12 as stepper driver temperature sensor on MB
M308 S13 Y"drivers" P"1.dummy" A"3HC-Drivers"               ; defines sensor 13 as stepper driver temperature sensor on 3HC
M950 F4 C"out4" Q500                                        ; create fan #4
M106 P4 C"PCB Fans" L0.1 X1 H10:11:12:13 T30:50 B0.1        ; configure fan #4

; LED
M950 F5 C"out5" Q3000000        ; create led as "fan 5"
M106 P5 C"LED" S1 B0.1 H-1      ; configure led

; Tools
M563 P1 S"Rapido" D0 H1 F1      ; create tool #1
M568 P1 R0 S10                  ; set initial tool #1 active and standby temperatures to 0C

;M563 P0 D0:1 S"Head12"			; creat tool #1 (0)
;M568 P0 X-83.5					;Set offset in X 64 + 6 + 27/2= 83.5
;M567 P0 E1:1				; Mixing extruder

M563 P2 S"Touch probe"          ; create tool #2
M568 P2 X30 Y0 Z-21.5           ; set custom offsets for tool #2

; GPIO Pins
M950 P1 C"!io8.out"             ; allocate GPIO port 1 to GPIO pin IO_0 on 3HC inverted 
;M950 P2 C"!1.io1.out"           ; allocate GPIO port 2 to GPIO pin IO_1 on 3HC inverted
M42 P1 S0                       ; disabe P1 by default
;M42 P2 S0                       ; disabe P2 by default


; Miscellaneous
M501                                                ; load saved parameters from non-volatile memory
T0                                                  ; select first tool
;M572 D0 S0.1                                        ; set initial pressure advance value
M98 P"1:/macros/Offset Directory/G54 Bed offset"    ; call initial G54 offset
;M98 P"0:/macros/Offset Directory/G54 Plate Offset"  ; call offset ALU
M912 P0 S-7									        ; offset MCU temp sensor
